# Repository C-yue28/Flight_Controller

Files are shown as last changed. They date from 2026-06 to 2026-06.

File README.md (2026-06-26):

<h1>Custom Flight Controller</h1>

<h3>What is it?</h3>
<p>This is a custom flight controller with onboard LiPo charging capabilities and buck converters for 3V bus as well as support for 6 external motors (3 DC, 3 servo) and 7-pin breakout for external sensor array. USB-UART bus for uploading firmware via serial. Internal power paths for limited high-current motor handling; however most motor wiring will most likely have to be done externally due to PCB limitations.</p>

<h3>Why did I make this?</h3>
<p>Flight has always been something that has fascinated me and so far my only experience has been with assembling premade drone kits or glider kits. I want to be able to go out and fly something that I made essentially from scratch. I have this vision of myself standing on the roof, tossing the plane off, and watching it fly up into the sky, and then looking at the camera feed to see the world from up high.</p>

<h3>Main components/features</h3>
<ol>
  <li>ESP32-S3-WROOM-1U - Central processor</li>
  <li>BMS management circuitry; computer is powered by 3S LiPo battery</li>
  <li>IMU (6-axis; accelerometer/gyroscope)</li>
  <li>Pressure sensor (for altitude)</li>
  <li>OV5640 Camera (external)</li>
  <li>Miscellaneous: external 2.4ghz antenna capability; dual USB-C for charging/data; external microSD support</li>
</ol>

<h3>Firmware brief description</h3>
- Modular handling of all sensors with interrupts configured to save battery power
- Verbose error/initialization logging to detect I2C issues
- Ability to log data to microSD card

<h3>Images</h3>

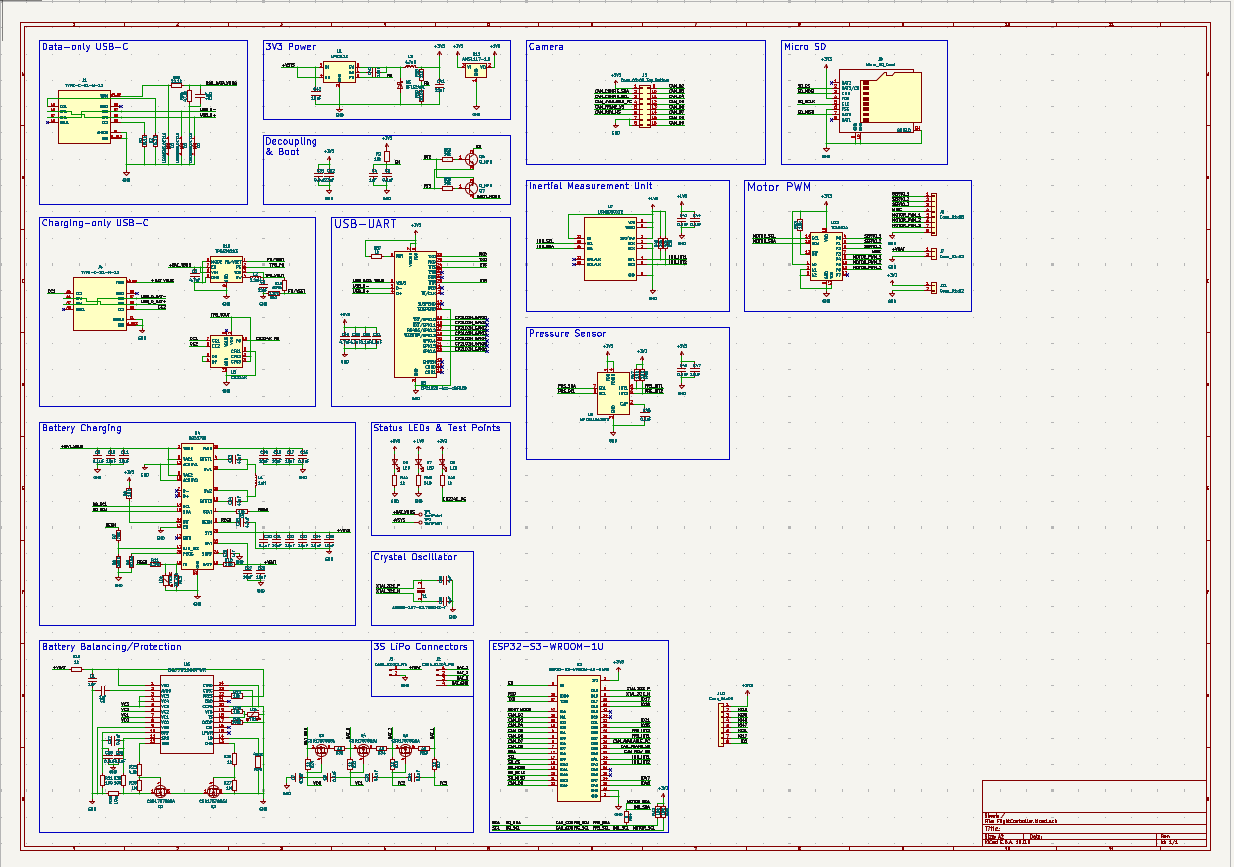
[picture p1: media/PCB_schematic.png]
Schematic


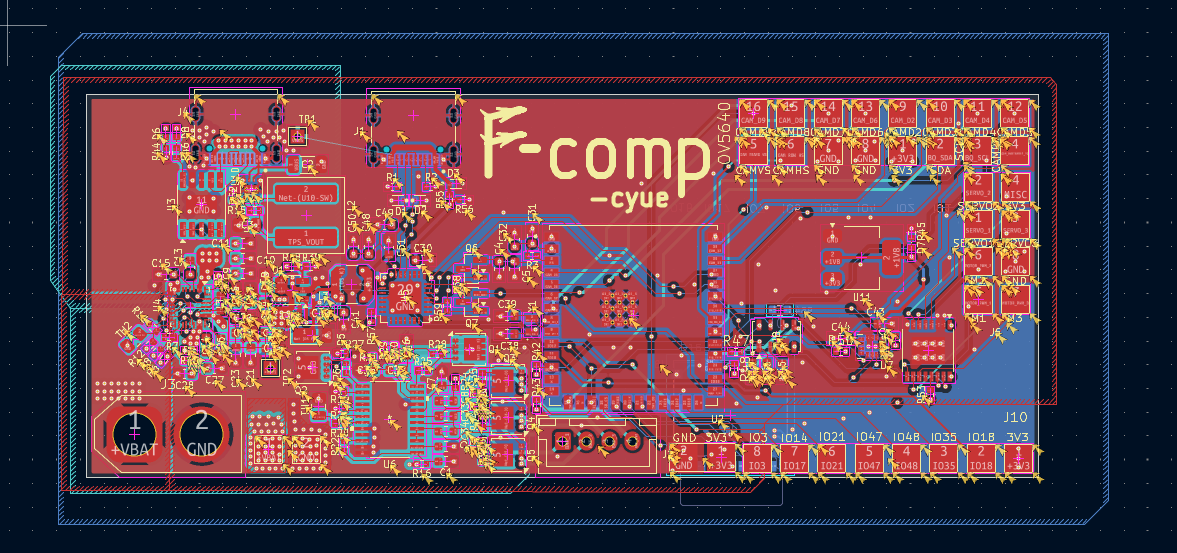
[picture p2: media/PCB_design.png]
PCB design


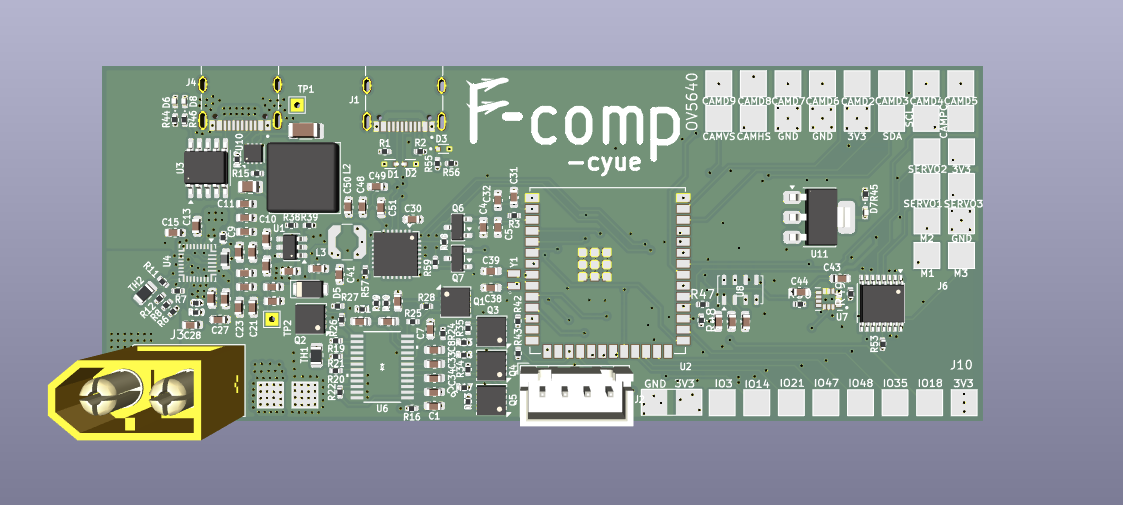
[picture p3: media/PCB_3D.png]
3D Model


<h3>External sources (for the LSM6DSOX firmware libraries)</h3>

[Base LSM6DS Adafruit library](https://github.com/adafruit/Adafruit_LSM6DS/blob/master/examples/adafruit_lsm6ds_unifiedsensors/adafruit_lsm6ds_unifiedsensors.ino)

### Dependencies of this library:

[Adafruit_BusIO](https://github.com/adafruit/Adafruit_BusIO/tree/master)

[Adafruit_Sensor](https://github.com/adafruit/Adafruit_Sensor/tree/master)

<h3>BOM</h3>

| Item | Price | Distributor/Supplier |
|---|---|---|
| PCB | 47.9  | JLCPCB |
| Stencil  | 7.16  | JLCPCB |
| Shipping | 24.15 | JLCPCB |
| Total | 79.21 | |

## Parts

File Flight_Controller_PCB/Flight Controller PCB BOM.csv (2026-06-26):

Designator | Footprint | Quantity | Value | URL | Cost | Notes
C1, C30, C4, C6 | 0603 | 4 | 1uF | https://www.lcsc.com/product-detail/C128624.html | 1.3 | I may already have these
C10, C11, C17, C18, C19, C21, C22, C23, C24, C25, C27, C28, C42 | 0603 | 13 | 10uF | https://www.lcsc.com/product-detail/C22367825.html | 1.16 | I may already have these
C13, C14 | 0603 | 2 | 47nF | 0603B473K500NT | FH | Price | In Stock | LCSC Electronics | 0.61
C15, C48, C49 | 0603 | 3 | 4.7uF | https://www.lcsc.com/product-detail/C5252400.html | 0.45 | I may already have these
C16, C20, C31, C33, C34, C35, C36, C37, C43, C44, C45, C46, C5, C50, C51, C7, C8, C9 | 0603 | 18 | 0.1uF | https://www.lcsc.com/product-detail/C125205.html | 0.81 | I may already have these
C2 | 1206 | 1 | 4.7uF | https://www.lcsc.com/product-detail/C22399656.html | 0.85
C26 | 0603 | 1 | 1nF | https://www.lcsc.com/product-detail/C44369.html | 0.52
C3 | 0805 | 1 | 22uF | (included below) | n/a | I decided to just use a smaller footprint to save some money
C32, C41 | 0603 | 2 | 22uF | https://www.digikey.com/en/products/detail/samsung-electro-mechanics/CL10A226MP8NUNE/3886932 | 0.64
C38, C39 | 0603 | 2 | 4pF | https://www.lcsc.com/product-detail/C1668.html | 0.42
C40 | 0603 | 1 | 10nF | https://www.lcsc.com/product-detail/C100042.html | 0.61
D1, D2, D3 | TVS_LESD5D5.0CT1G | 3 | LESD5D5.0CT1G | https://www.lcsc.com/product-detail/C5246195.html | 0.36
D5 | D_PowerDI-123 | 1 | DFLS240L
D6, D7, D8 | 0402 | 3 | LED | https://www.lcsc.com/product-detail/Light-Emitting-Diodes-LED_YONGYUTAI-YLED0402G_C20608784.html | 0.76
J1, J4 | HRO_TYPE-C-31-M-12 | 2 | TYPE-C-31-M-12 | (I already have these) | n/a
J10, J6 | TestPoint_THTPad_4.0x4.0mm_Drill2.0mm | 2 | Conn_01x08 | n/a
J11, J7 | TestPoint_THTPad_4.0x4.0mm_Drill2.0mm | 2 | Conn_01x02 | n/a
J2 | JST_XH_B4B-XH-A_1x04_P2.50mm_Vertical | 1 | Conn_01x04_Pin | https://www.lcsc.com/product-detail/C144395.html | 0.58
J3 | AMASS_XT60-M_1x02_P7.20mm_Vertical | 1 | Conn_01x02_Pin | https://www.lcsc.com/product-detail/C98733.html | 0.4
J5 | TestPoint_THTPad_2.0x2.0mm_Drill1.0mm | 1 | Conn_02x09_Top_Bottom | n/a
J8 | microSD_HC_Molex_104031-0811 | 1 | Micro_SD_Card | https://www.lcsc.com/product-detail/C585350.html | 0.68
L1 | 0603 | 1 | 1uH | https://www.lcsc.com/product-detail/C5443610.html | 0.42
L2 | 1008 | 1 | 2.2uH | https://www.digikey.com/en/products/detail/shenzhen-sunlord-electronics-co-ltd/SPH252012H2R2MT/14545122 | 0.33
L3 | L_Abracon_ASPI-4030S | 1 | 4.7uH | https://www.digikey.com/en/products/detail/abracon-llc/ASPI-4030S-4R7M-T/4215208 | 0.27
Q1, Q2, Q3, Q4, Q5 | VSON-8_3.3x3.3mm_P0.65mm_NexFET | 5 | CSD17578Q5A | https://www.lcsc.com/product-detail/C2871447.html | 2.41
Q6, Q7 | SOT-23 | 2 | Q_NPN | https://www.lcsc.com/product-detail/C49581.html | 0.79
R1, R2 | 0402 | 2 | 5.1k | https://www.digikey.com/en/products/detail/yageo/RC0402FR-075K1L/726624 | 0.2
R10, R30, R31 | 0402 | 3 | 100 | https://www.digikey.com/en/products/detail/vishay-dale/RCA0402100RFKEDHP/6561236 | 0.3
R11 | 0402 | 1 | 5.24k | https://www.digikey.com/en/products/detail/bourns-inc/CR0402-FX-5231GLF/4698012 | 0.1
R12 | 0402 | 1 | 30.31k | https://www.digikey.com/en/products/detail/vishay-dale/RCS040230K1FKED/5867856 | 0.13
R15 | 0402 | 1 | 619k | https://www.digikey.com/en/products/detail/stackpole-electronics-inc/RMCF0402FT619K/1714833 | 0.1
R16, R17, R18, R23, R24, R26, R44, R46, R57 | 0402 | 9 | 1k | https://www.digikey.com/en/products/detail/vishay/MCS04020C1001FE000/462974 | 0.28 | I may already have these
R19 | 0402 | 1 | 450k | https://www.digikey.com/en/products/detail/vishay-dale/CRCW0402453KFKED/1178309 | 0.1
R20, R22, R3, R42, R43, R49, R5, R50, R53, R58, R59, R9 | 0402 | 12 | 10k | https://www.digikey.com/en/products/detail/vishay-dale/RCA040210K0FKED/4946751 | 0.66 | I may already have these
R21 | 0402 | 1 | 196k | https://www.digikey.com/en/products/detail/stackpole-electronics-inc/RMCF0402FT196K/1761755 | 0.1
R25 | 0402 | 1 | 4.5k | http://digikey.com/en/products/detail/vishay-dale/TNPW04024K53BEED/1606384 | 0.26
R27, R28 | 0402 | 2 | 1M | https://www.digikey.com/en/products/detail/yageo/RC0402FR-071ML/726515 | 0.2
R29 | 0402 | 1 | 10m | https://www.digikey.com/en/products/detail/thin-film-technology-corp/D1MPC0402RR010FF-T10/16735271 | 0.28
R33, R34, R35 | 0805 | 3 | 45 | MBB02070C4539FRP00 (1W, 45.3 OHM): https://www.mouser.com/c/passive-components/resistors/?resistance=45.3%20Ohms&instock=y | 1.14
R38 | 0402 | 1 | 51k | https://www.digikey.com/en/products/detail/stackpole-electronics-inc/RMCF0402FT51K0/2417446 | 0.1
R39 | 0402 | 1 | 16.6k | https://www.digikey.com/en/products/detail/vishay-dale/CRCW040216K9FKEDC/7925759 | 0.1
R45 | 0402 | 1 | 510 | https://www.digikey.com/en/products/detail/koa-speer-electronics-inc/RK73H1ETTP5100F/9844229 | 0.1
R52 | 0402 | 1 | 137k | https://www.digikey.com/en/products/detail/yageo/RC0402FR-07137KL/5280832 | 0.1
R54 | 0603 | 1 | 0 | n/a
R55 | 0402 | 1 | 22.1k | https://www.digikey.com/en/products/detail/yageo/RT0402FRE0722K1L/1071878 | 0.1
R56 | 0402 | 1 | 47.5k | https://www.digikey.com/en/products/detail/yageo/RC0402FR-0747K5L/726617 | 0.1
R6 | 0402 | 1 | 10.5k | https://www.digikey.com/en/products/detail/yageo/RT0402FRE0710K5L/1071707 | 0.1
R7 | 0402 | 1 | 75k | https://www.digikey.com/en/products/detail/yageo/RT0402DRE0775KL/1071646 | 0.1
R8 | 0402 | 1 | 160k | https://www.digikey.com/en/products/detail/stackpole-electronics-inc/RMCF0402FT160K/1714462 | 0.1
TH1, TH2 | 0805 | 2 | 10k | https://www.digikey.com/en/products/detail/tdk/B57471V2103J062/3829885 | 0.62
TP1, TP2 | TestPoint_THTPad_1.5x1.5mm_Drill0.7mm | 2 | TestPoint | n/a
U1 | SOT-23-6 | 1 | AP3211K | https://www.digikey.com/en/products/detail/diodes-incorporated/AP2112K-3-3TRG1/4470746 | 0.25 | I may already have this
U10 | SOT-583-8 | 1 | TPS629203 | https://www.digikey.com/en/products/detail/texas-instruments/TPS629203DRLR/16516661 | 1.08
U11 | SOT-223-3_TabPin2 | 1 | AMS1117-1.8 | https://www.digikey.com/en/products/detail/evvo/AMS1117-1-8/24370064 | 0.3
U12 | TSSOP-16-1EP_4.4x5mm_P0.65mm | 1 | TCA9534 | https://www.digikey.com/en/products/detail/texas-instruments/TCA9534PWR/5004966 | 1.53
U2 | XCVR_ESP32-S3-WROOM-1U-N4R8 | 1 | ESP32-S3-WROOM-1U-N4R8 | https://www.digikey.com/en/products/detail/espressif-systems/ESP32-S3-WROOM-1U-N16R8/16162641 | 6.76
U3 | SSOP-10-1EP_3.9x4.9mm_P1mm_EP2.1x3.3mm | 1 | CH224K | https://www.lcsc.com/product-detail/C970725.html | 0.62
U4 | Texas_RQM0029A_VQFN-29_4x4mm_P0.4mm | 1 | BQ25798 | https://www.digikey.com/en/products/detail/texas-instruments/BQ25798RQMR/15666783 | 5.2
U5 | QFN-28-1EP_5x5mm_P0.5mm_EP3.35x3.35mm | 1 | CP2102N-Axx-xQFN28 | https://www.digikey.com/en/products/detail/silicon-labs/CP2102N-A02-GQFN28/9863477 | 5.1
U6 | PW24_TEX | 1 | BQ7791500PWR | https://www.digikey.com/en/products/detail/texas-instruments/BQ7791500PWR/9593372 | 2.05
U7 | PQFN50P250X300X86-14N | 1 | LSM6DSOXTR | https://estore.st.com/en/lsm6dsotr-cpn.html | 5.32 | LSM6DSOTR
U9 | Bosch_LGA-8_2.5x2.5mm_P0.65mm_ClockwisePinNumbering | 1 | BME280 | https://www.digikey.com/en/products/detail/bosch-sensortec/BME280/6136306 | 4
Y1 | XTAL_ABS06-107-32.768KHZ-T | 1 | ABS06-107-32.768KHZ-T | https://www.digikey.com/en/products/detail/abracon-llc/ABS06-107-32-768KHZ-T/4291565 | 0.83
 |  |  |  |  | 52.78

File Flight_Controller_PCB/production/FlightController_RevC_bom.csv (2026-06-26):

Designator | Footprint | Quantity | Value | LCSC Part #
C1, C30, C4, C6 | 0603 | 4 | 1uF
C10, C11, C17, C18, C19, C21, C22, C23, C24, C25, C27, C28, C42 | 0603 | 13 | 10uF
C13, C14 | 0603 | 2 | 47nF
C15, C48, C49 | 0603 | 3 | 4.7uF
C16, C20, C31, C33, C34, C35, C36, C37, C43, C44, C45, C46, C5, C50, C51, C7, C8, C9 | 0603 | 18 | 0.1uF
C2 | 1206 | 1 | 4.7uF
C26 | 0603 | 1 | 1nF
C3 | 0805 | 1 | 22uF
C32, C41 | 0603 | 2 | 22uF
C38, C39 | 0603 | 2 | 4pF
C40 | 0603 | 1 | 10nF
D1, D2, D3 | TVS_LESD5D5.0CT1G | 3 | LESD5D5.0CT1G
D5 | D_PowerDI-123 | 1 | DFLS240L
D6, D7, D8 | 0402 | 3 | LED
J1, J4 | HRO_TYPE-C-31-M-12 | 2 | TYPE-C-31-M-12
J10, J6 | TestPoint_THTPad_4.0x4.0mm_Drill2.0mm | 2 | Conn_01x08
J11, J7 | TestPoint_THTPad_4.0x4.0mm_Drill2.0mm | 2 | Conn_01x02
J2 | JST_XH_B4B-XH-A_1x04_P2.50mm_Vertical | 1 | Conn_01x04_Pin
J3 | AMASS_XT60-M_1x02_P7.20mm_Vertical | 1 | Conn_01x02_Pin
J5 | TestPoint_THTPad_2.0x2.0mm_Drill1.0mm | 1 | Conn_02x09_Top_Bottom
J8 | microSD_HC_Molex_104031-0811 | 1 | Micro_SD_Card
L1 | 0603 | 1 | 1uH
L2 | 1008 | 1 | 2.2uH
L3 | L_Abracon_ASPI-4030S | 1 | 4.7uH
Q1, Q2, Q3, Q4, Q5 | VSON-8_3.3x3.3mm_P0.65mm_NexFET | 5 | CSD17578Q5A
Q6, Q7 | SOT-23 | 2 | Q_NPN
R1, R2 | 0402 | 2 | 5.1k
R10, R30, R31 | 0402 | 3 | 100
R11 | 0402 | 1 | 5.24k
R12 | 0402 | 1 | 30.31k
R15 | 0402 | 1 | 619k
R16, R17, R18, R23, R24, R26, R44, R46, R57 | 0402 | 9 | 1k
R19 | 0402 | 1 | 450k
R20, R22, R3, R42, R43, R49, R5, R50, R53, R58, R59, R9 | 0402 | 12 | 10k
R21 | 0402 | 1 | 196k
R25 | 0402 | 1 | 4.5k
R27, R28 | 0402 | 2 | 1M
R29 | 0402 | 1 | 10m
R33, R34, R35 | 0805 | 3 | 45
R38 | 0402 | 1 | 51k
R39 | 0402 | 1 | 16.6k
R45 | 0402 | 1 | 510
R52 | 0402 | 1 | 137k
R54 | 0603 | 1 | 0
R55 | 0402 | 1 | 22.1k
R56 | 0402 | 1 | 47.5k
R6 | 0402 | 1 | 10.5k
R7 | 0402 | 1 | 75k
R8 | 0402 | 1 | 160k
TH1, TH2 | 0805 | 2 | 10k
TP1, TP2 | TestPoint_THTPad_1.5x1.5mm_Drill0.7mm | 2 | TestPoint
U1 | SOT-23-6 | 1 | AP3211K
U10 | SOT-583-8 | 1 | TPS629203
U11 | SOT-223-3_TabPin2 | 1 | AMS1117-1.8
U12 | TSSOP-16-1EP_4.4x5mm_P0.65mm | 1 | TCA9534
U2 | XCVR_ESP32-S3-WROOM-1U-N4R8 | 1 | ESP32-S3-WROOM-1U-N4R8
U3 | SSOP-10-1EP_3.9x4.9mm_P1mm_EP2.1x3.3mm | 1 | CH224K
U4 | Texas_RQM0029A_VQFN-29_4x4mm_P0.4mm | 1 | BQ25798
U5 | QFN-28-1EP_5x5mm_P0.5mm_EP3.35x3.35mm | 1 | CP2102N-Axx-xQFN28
U6 | PW24_TEX | 1 | BQ7791500PWR
U7 | PQFN50P250X300X86-14N | 1 | LSM6DSOXTR
U9 | Bosch_LGA-8_2.5x2.5mm_P0.65mm_ClockwisePinNumbering | 1 | BME280
Y1 | XTAL_ABS06-107-32.768KHZ-T | 1 | ABS06-107-32.768KHZ-T

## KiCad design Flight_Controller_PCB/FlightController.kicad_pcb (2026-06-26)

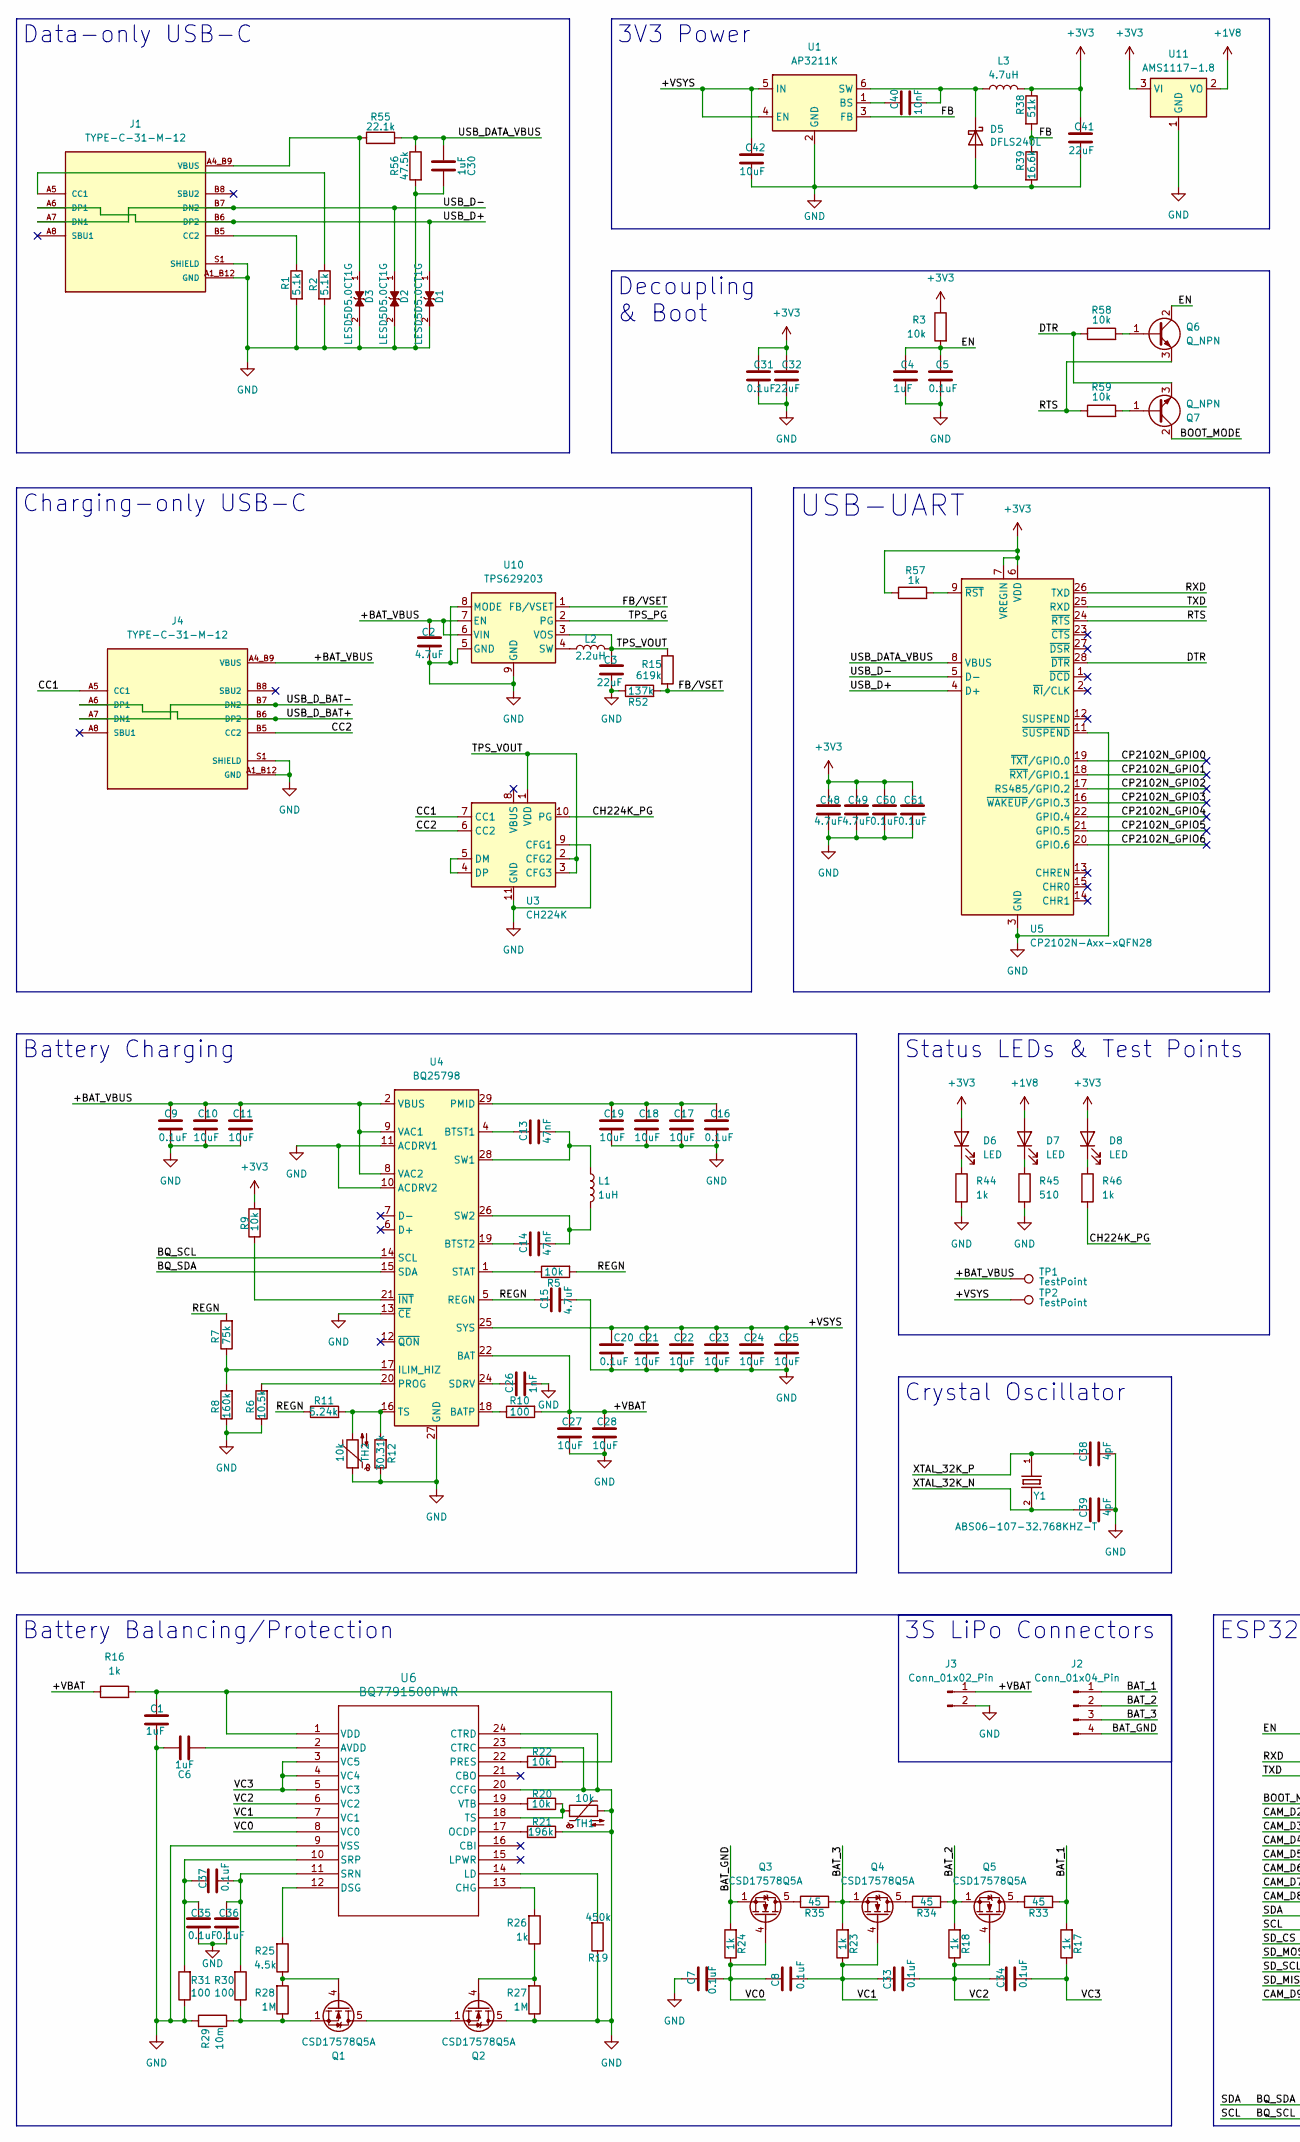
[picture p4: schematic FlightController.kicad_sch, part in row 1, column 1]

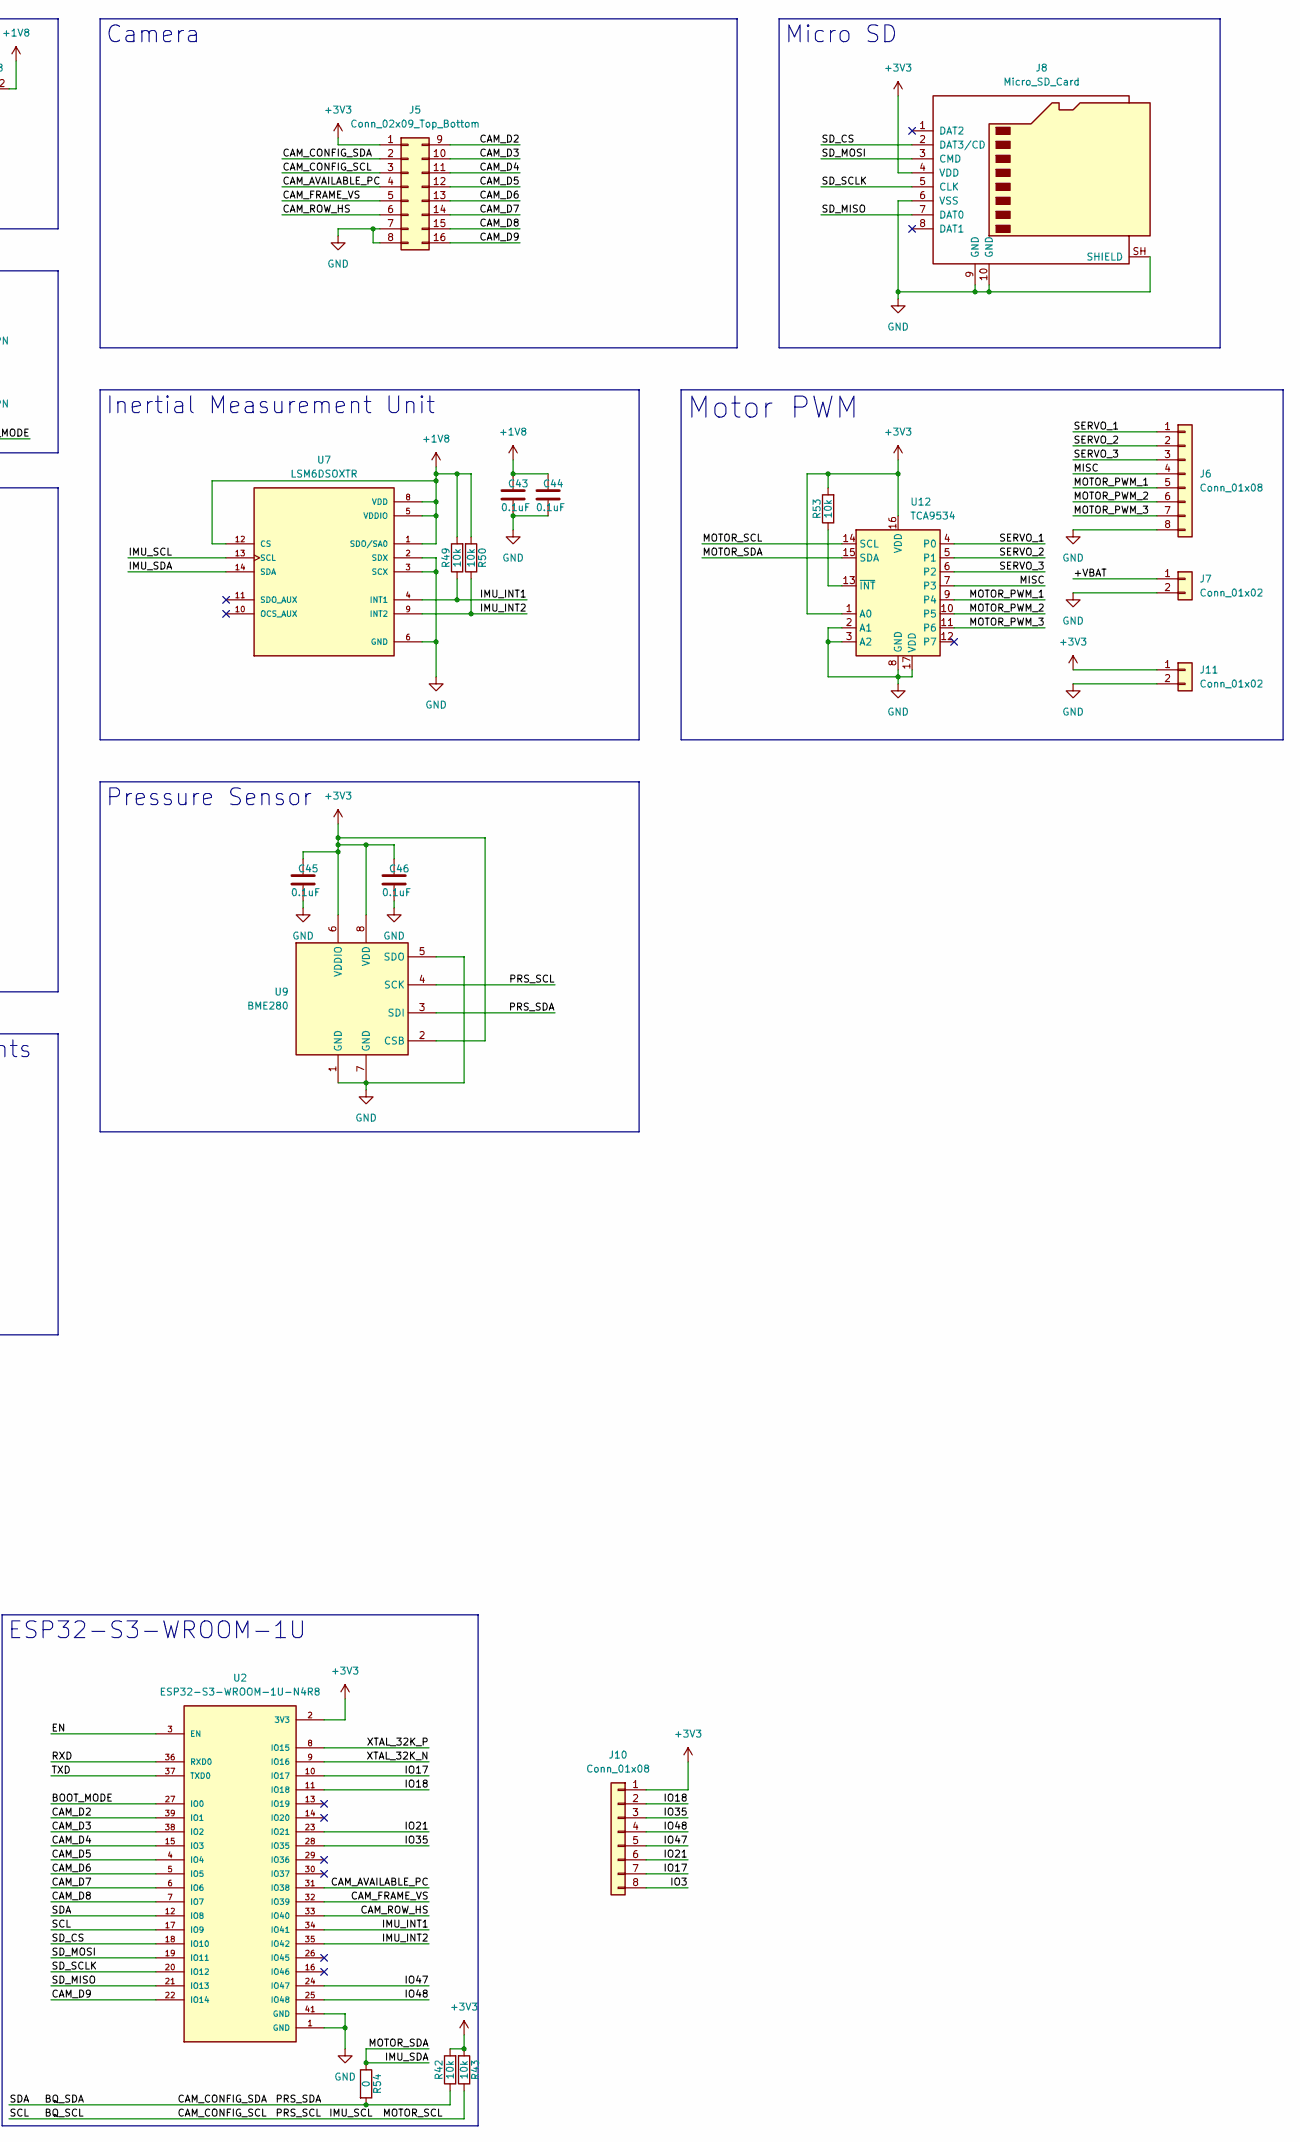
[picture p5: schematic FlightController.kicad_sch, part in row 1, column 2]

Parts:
C1, C4, C6, C30: 1uF; C_0603_1608Metric
C2: 4.7uF; C_1206_3216Metric
C3: 22uF; C_0805_2012Metric
C5, C7, C8, C9, C16, C20, C31, C33, C34, C35, C36, C37, C43, C44, C45, C46, C50, C51: 0.1uF; C_0603_1608Metric
C10, C11, C17, C18, C19, C21, C22, C23, C24, C25, C27, C28, C42: 10uF; C_0603_1608Metric
C13, C14: 47nF; C_0603_1608Metric
C15, C48, C49: 4.7uF; C_0603_1608Metric
C26: 1nF; C_0603_1608Metric
C32, C41: 22uF; C_0603_1608Metric
C38, C39: 4pF; C_0603_1608Metric
C40: 10nF; C_0603_1608Metric
D1, D2, D3: LESD5D5.0CT1G; TVS_LESD5D5.0CT1G; PARTREV O
D5: DFLS240L; D_PowerDI-123
D6, D7, D8: LED; LED_0402_1005Metric
J1, J4: TYPE-C-31-M-12; HRO_TYPE-C-31-M-12; PARTREV 2020.12.08
J2: Conn_01x04_Pin; JST_XH_B4B-XH-A_1x04_P2.50mm_Vertical
J3: Conn_01x02_Pin; AMASS_XT60-M_1x02_P7.20mm_Vertical
J5: Conn_02x09_Top_Bottom; TestPoint_THTPad_2.0x2.0mm_Drill1.0mm
J6, J10: Conn_01x08; TestPoint_THTPad_4.0x4.0mm_Drill2.0mm
J7, J11: Conn_01x02; TestPoint_THTPad_4.0x4.0mm_Drill2.0mm
J8: Micro_SD_Card; microSD_HC_Molex_104031-0811
L1: 1uH; L_0603_1608Metric
L2: 2.2uH; L_1008_2520Metric
L3: 4.7uH; L_Abracon_ASPI-4030S
Q1, Q2, Q3, Q4, Q5: CSD17578Q5A; VSON-8_3.3x3.3mm_P0.65mm_NexFET
Q6, Q7: Q_NPN; SOT-23
R1, R2: 5.1k; R_0402_1005Metric
R3, R5, R9, R20, R22, R42, R43, R49, R50, R53, R58, R59: 10k; R_0402_1005Metric
R6: 10.5k; R_0402_1005Metric
R7: 75k; R_0402_1005Metric
R8: 160k; R_0402_1005Metric
R10, R30, R31: 100; R_0402_1005Metric
R11: 5.24k; R_0402_1005Metric
R12: 30.31k; R_0402_1005Metric
R15: 619k; R_0402_1005Metric
R16, R17, R18, R23, R24, R26, R44, R46, R57: 1k; R_0402_1005Metric
R19: 450k; R_0402_1005Metric
R21: 196k; R_0402_1005Metric
R25: 4.5k; R_0402_1005Metric
R27, R28: 1M; R_0402_1005Metric
R29: 10m; R_0402_1005Metric
R33, R34, R35: 45; R_0805_2012Metric_Pad1.20x1.40mm_HandSolder
R38: 51k; R_0402_1005Metric
R39: 16.6k; R_0402_1005Metric
R45: 510; R_0402_1005Metric
R52: 137k; R_0402_1005Metric
R54: 0; R_0603_1608Metric
R55: 22.1k; R_0402_1005Metric
R56: 47.5k; R_0402_1005Metric
TH1, TH2: 10k; R_0805_2012Metric
TP1, TP2: TestPoint; TestPoint_THTPad_1.5x1.5mm_Drill0.7mm
U1: AP3211K; SOT-23-6
U2: ESP32-S3-WROOM-1U-N4R8; XCVR_ESP32-S3-WROOM-1U-N4R8; PARTREV v1.1; DigiKey_Part_Number 1965-ESP32-S3-WROOM-1U-N4R8CT-ND
U3: CH224K; SSOP-10-1EP_3.9x4.9mm_P1mm_EP2.1x3.3mm
U4: BQ25798; Texas_RQM0029A_VQFN-29_4x4mm_P0.4mm
U5: CP2102N-Axx-xQFN28; QFN-28-1EP_5x5mm_P0.5mm_EP3.35x3.35mm
U6: BQ7791500PWR; PW24_TEX
U7: LSM6DSOXTR; PQFN50P250X300X86-14N; PARTREV 3.0; DigiKey_Part_Number 497-18367-1-ND
U9: BME280; Bosch_LGA-8_2.5x2.5mm_P0.65mm_ClockwisePinNumbering
U10: TPS629203; SOT-583-8
U11: AMS1117-1.8; SOT-223-3_TabPin2
U12: TCA9534; TSSOP-16-1EP_4.4x5mm_P0.65mm
Y1: ABS06-107-32.768KHZ-T; XTAL_ABS06-107-32.768KHZ-T; DigiKey_Part_Number 535-12373-1-ND

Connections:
+1V8: C43.1, C44.1, D7.2 (A), R49.2, R50.2, U7.1 (SDO/SA0), U7.5 (VDDIO), U7.8 (VDD), U7.12 (CS), U11.2 (VO)
+3V3: C31.1, C32.1, C41.1, C45.1, C46.1, C48.1, C49.1, C50.1, C51.1, D6.2 (A), D8.2 (A), J5.1, J8.4 (VDD), J10.1, J11.1, L3.2, R3.1, R9.2, R38.1, R42.2, R43.2, R53.2, R57.1, U2.2 (3V3), U5.6 (VDD), U5.7 (VREGIN), U9.2 (CSB), U9.6 (VDDIO), U9.8 (VDD), U11.3 (VI), U12.1 (A0), U12.16 (VDD)
/+VBAT: C27.1, C28.1, J3.1, J7.1, R10.2, R16.1, U4.22 (BAT), U4.23 (BAT)
/+VSYS: C20.1, C21.1, C22.1, C23.1, C24.1, C25.1, C42.1, TP2.1 (1_1), U1.4 (EN), U1.5 (IN), U4.25 (SYS)
/BAT_1: J2.1, R17.2, R33.2
/BAT_2: J2.2, Q5.1 (S), Q5.2 (S), Q5.3 (S), R18.2, R34.2
/BAT_3: J2.3, Q4.1 (S), Q4.2 (S), Q4.3 (S), R23.2, R35.2
/BAT_GND: J2.4, Q3.1 (S), Q3.2 (S), Q3.3 (S), R24.2
/BOOT_MODE: Q7.2 (C), U2.27 (IO0)
/BQ_SCL: J5.3, R43.1, U2.17 (IO9), U4.14 (SCL), U7.13 (SCL), U9.4 (SCK), U12.14 (SCL)
/BQ_SDA: J5.2, R42.1, R54.2, U2.12 (IO8), U4.15 (SDA), U9.3 (SDI)
/CAM_AVAILABLE_PC: J5.4, U2.31 (IO38)
/CAM_D2: J5.9, U2.39 (IO1)
/CAM_D3: J5.10, U2.38 (IO2)
/CAM_D4: J5.11, U2.15 (IO3)
/CAM_D5: J5.12, U2.4 (IO4)
/CAM_D6: J5.13, U2.5 (IO5)
/CAM_D7: J5.14, U2.6 (IO6)
/CAM_D8: J5.15, U2.7 (IO7)
/CAM_D9: J5.16, U2.22 (IO14)
/CAM_FRAME_VS: J5.5, U2.32 (IO39)
/CAM_ROW_HS: J5.6, U2.33 (IO40)
/CC1: J4.A5 (CC1), U3.7 (CC1)
/CC2: J4.B5 (CC2), U3.6 (CC2)
/CH224K_PG: R46.2, U3.10 (PG)
/CP2102N_GPIO0: U5.19 (~TXT/GPIO.0)
/CP2102N_GPIO1: U5.18 (~RXT/GPIO.1)
/CP2102N_GPIO2: U5.17 (RS485/GPIO.2)
/CP2102N_GPIO3: U5.16 (~WAKEUP/GPIO.3)
/CP2102N_GPIO4: U5.22 (GPIO.4)
/CP2102N_GPIO5: U5.21 (GPIO.5)
/CP2102N_GPIO6: U5.20 (GPIO.6)
/DTR: Q7.3 (E), R58.1, U5.28 (~DTR)
/EN: C4.1, C5.1, Q6.2 (C), R3.2, U2.3 (EN)
/FB: R38.2, R39.1, U1.3 (FB)
/FB/VSET: R15.2, R52.2, U10.1 (FB/VSET)
/IMU_INT1: R49.1, U2.34 (IO41), U7.4 (INT1)
/IMU_INT2: R50.1, U2.35 (IO42), U7.9 (INT2)
/IMU_SDA: R54.1, U7.14 (SDA), U12.15 (SDA)
/IO3: J10.8
/IO17: J10.7, U2.10 (IO17)
/IO18: J10.2, U2.11 (IO18)
/IO21: J10.6, U2.23 (IO21)
/IO35: J10.3, U2.28 (IO35)
/IO47: J10.5, U2.24 (IO47)
/IO48: J10.4, U2.25 (IO48)
/MISC: J6.4, U12.7 (P3)
/MOTOR_PWM_1: J6.5, U12.9 (P4)
/MOTOR_PWM_2: J6.6, U12.10 (P5)
/MOTOR_PWM_3: J6.7, U12.11 (P6)
/REGN: C15.1, R5.2, R7.2, R11.1, U4.5 (REGN)
/RTS: Q6.3 (E), R59.1, U5.24 (~RTS)
/RXD: U2.36 (RXD0), U5.26 (TXD)
/SD_CS: J8.2 (DAT3/CD), U2.18 (IO10)
/SD_MISO: J8.7 (DAT0), U2.21 (IO13)
/SD_MOSI: J8.3 (CMD), U2.19 (IO11)
/SD_SCLK: J8.5 (CLK), U2.20 (IO12)
/SERVO_1: J6.1, U12.4 (P0)
/SERVO_2: J6.2, U12.5 (P1)
/SERVO_3: J6.3, U12.6 (P2)
/TPS_PG: U10.2 (PG)
/TPS_VOUT: C3.1, L2.1, R15.1, U3.1 (VDD), U3.2 (CFG2), U3.3 (CFG3), U10.3 (VOS)
/TXD: U2.37 (TXD0), U5.25 (RXD)
/USB_D+: D1.1, J1.A6 (DP1), J1.B6 (DP2), U5.4 (D+)
/USB_D-: D2.1, J1.A7 (DN1), J1.B7 (DN2), U5.5 (D-)
/USB_DATA_VBUS: C30.2, R55.2, R56.1, U5.8 (VBUS)
/USB_D_BAT+: J4.A6 (DP1), J4.B6 (DP2)
/USB_D_BAT-: J4.A7 (DN1), J4.B7 (DN2)
/VC0: C7.2, C8.2, Q3.4 (G), R24.1, U6.8 (VC0)
/VC1: C8.1, C33.2, Q4.4 (G), R23.1, U6.7 (VC1)
/VC2: C33.1, C34.2, Q5.4 (G), R18.1, U6.6 (VC2)
/VC3: C34.1, R17.1, U6.3 (VC5), U6.4 (VC4), U6.5 (VC3)
/XTAL_32K_N: C39.1, U2.9 (IO16), Y1.2
/XTAL_32K_P: C38.1, U2.8 (IO15), Y1.1
GND: C1.2, C2.2, C3.2, C4.2, C5.2, C6.1, C7.1, C9.2, C10.2, C11.2, C15.2, C16.2, C17.2, C18.2, C19.2, C20.2, C21.2, C22.2, C23.2, C24.2, C25.2, C26.2, C27.2, C28.2, C30.1, C31.2, C32.2, C35.1, C36.1, C38.2, C39.2, C41.2, C42.2, C43.2, C44.2, C45.2, C46.2, C48.2, C49.2, C50.2, C51.2, D1.2, D2.2, D3.2, D5.2 (A), J1.A1_B12 (GND), J1.B1_A12 (GND), J1.S1 (SHIELD), J1.S2 (SHIELD), J1.S3 (SHIELD), J1.S4 (SHIELD), J3.2, J4.A1_B12 (GND), J4.B1_A12 (GND), J4.S1 (SHIELD), J4.S2 (SHIELD), J4.S3 (SHIELD), J4.S4 (SHIELD), J5.7, J5.8, J6.8, J7.2, J8.6 (VSS), J8.9 (GND), J8.10 (GND), J8.SH (SHIELD), J11.2, Q2.5 (D), R1.2, R2.2, R6.1, R8.1, R12.1, R19.1, R21.1, R27.1, R29.2, R31.1, R39.2, R44.2, R45.2, R52.1, R56.2, TH1.2, TH2.1, U1.2 (GND), U2.1 (GND), U2.40 (GND), U2.41 (GND), U2.41_1 (GND), U2.41_2 (GND), U2.41_3 (GND), U2.41_4 (GND), U2.41_5 (GND), U2.41_6 (GND), U2.41_7 (GND), U2.41_8 (GND), U2.41_9 (GND), U3.9 (CFG1), U3.11 (GND), U4.10 (ACDRV2), U4.11 (ACDRV1), U4.13 (~CE), U4.27 (GND), U5.3 (GND), U5.11 (~SUSPEND), U5.29 (GND), U6.9 (VSS), U6.20 (CCFG), U6.23 (CTRC), U6.24 (CTRD), U7.2 (SDX), U7.3 (SCX), U7.6 (GND), U7.7 (GND), U9.1 (GND), U9.5 (SDO), U9.7 (GND), U10.5 (GND), U10.8 (MODE), U10.9 (GND), U11.1 (GND), U12.2 (A1), U12.3 (A2), U12.8 (GND), U12.17 (VDD)
unnamed: C40.2, D5.1 (K), L3.1, U1.6 (SW)
unnamed: D6.1 (K), R44.1
unnamed: D7.1 (K), R45.1
unnamed: D8.1 (K), R46.1
unnamed: J1.A5 (CC1), R2.1
unnamed: J1.B5 (CC2), R1.1
unnamed: Q1.5 (D), Q2.1 (S), Q2.2 (S), Q2.3 (S)
unnamed: Q1.4 (G), R25.1, R28.2
unnamed: Q1.1 (S), Q1.2 (S), Q1.3 (S), R28.1, R29.1, R30.1
unnamed: Q2.4 (G), R26.1, R27.2
unnamed: Q3.5 (D), R35.1
unnamed: Q4.5 (D), R34.1
unnamed: Q5.5 (D), R33.1
unnamed: Q6.1 (B), R58.2
unnamed: Q7.1 (B), R59.2
unnamed: C40.1, U1.1 (BS)
unnamed: U3.4 (DP), U3.5 (DM)
unnamed: R10.1, U4.18 (BATP)
unnamed: C13.1, U4.4 (BTST1)
unnamed: C14.1, U4.19 (BTST2)
unnamed: R7.1, R8.2, U4.17 (ILIM_HIZ)
unnamed: C16.1, C17.1, C18.1, C19.1, U4.29 (PMID)
unnamed: R6.2, U4.20 (PROG)
unnamed: C26.1, U4.24 (SDRV)
unnamed: R5.1, U4.1 (STAT)
unnamed: C13.2, L1.1, U4.28 (SW1)
unnamed: C14.2, L1.2, U4.26 (SW2)
unnamed: R11.2, R12.2, TH2.2, U4.16 (TS)
unnamed: R9.1, U4.21 (~INT)
unnamed: R57.2, U5.9 (~RST)
unnamed: C6.2, U6.2 (AVDD)
unnamed: R26.2, U6.13 (CHG)
unnamed: R25.2, U6.12 (DSG)
unnamed: R19.2, U6.14 (LD)
unnamed: R21.2, U6.17 (OCDP)
unnamed: R22.2, U6.22 (PRES)
unnamed: C36.2, C37.1, R30.2, U6.11 (SRN)
unnamed: C35.2, C37.2, R31.2, U6.10 (SRP)
unnamed: R20.1, TH1.1, U6.18 (TS)
unnamed: C1.1, R16.2, R22.1, U6.1 (VDD)
unnamed: R20.2, U6.19 (VTB)
unnamed: L2.2, U10.4 (SW)
unnamed: R53.1, U12.13 (~INT)

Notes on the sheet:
3S LiPo Connectors
ESP32-S3-WROOM-1U
Micro SD
Motor PWM
Camera
USB-UART
Decoupling & Boot
Data-only USB-C
Inertial Measurement Unit
Pressure Sensor
Battery Balancing/Protection
Battery Charging
3V3 Power
Charging-only USB-C
Crystal Oscillator
Status LEDs & Test Points

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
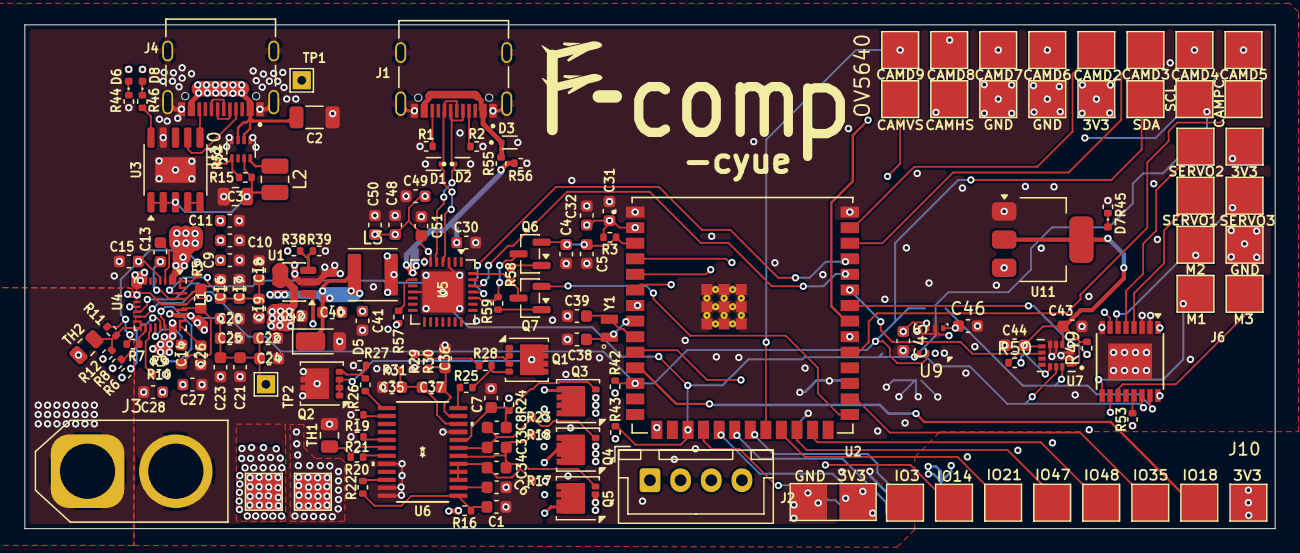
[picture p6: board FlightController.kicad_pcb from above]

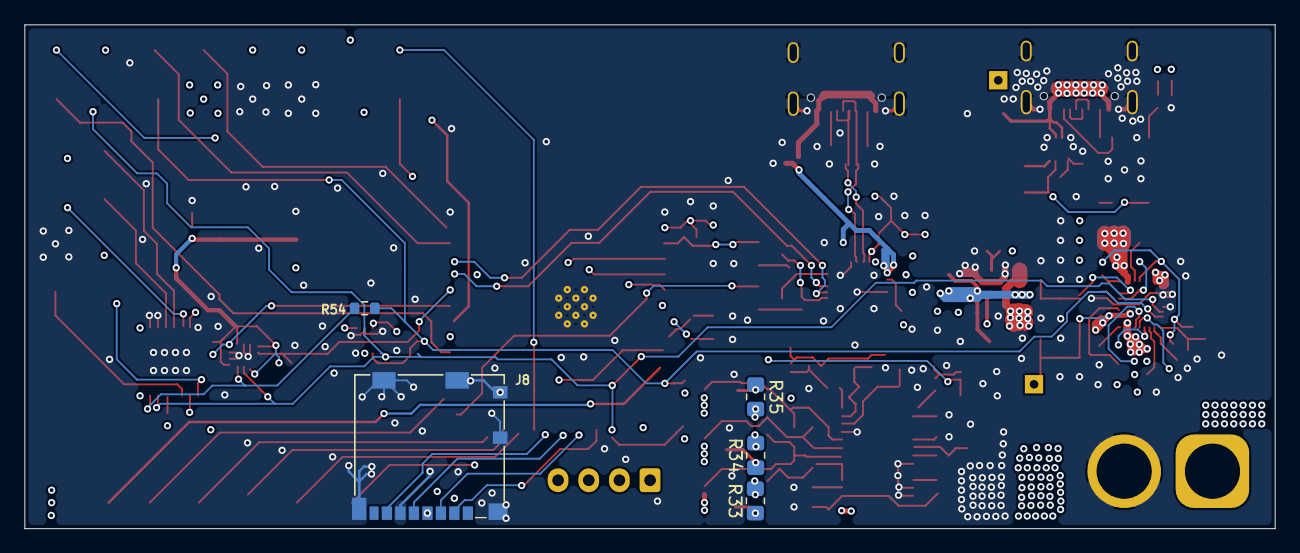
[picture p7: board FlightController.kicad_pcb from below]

Board: 6 copper layers, 102.0 x 41.1 mm, 139 parts (5 on the bottom side), 110 nets.

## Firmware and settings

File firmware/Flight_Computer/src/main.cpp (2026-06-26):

#include <Arduino.h>
#include <Wire.h>
#include <SD.h>
#include <SPI.h>

// Personal libraries
#include <BQ25798.h>
#include <TCA9534.h>
#include <OV5640.h>
#include <BME280.h>

// Open-source libraries
#include <Adafruit_LSM6DSOX.h>

#define ESP32_ADDR 0x67

// I2C pins

#define SDA 8
#define SCL 9

#define NUM_I2C_DEVICES 5
#define MAX_I2C_INIT_LOOPS 10

// External SD card

#define SD_CS 10
#define SD_MOSI 11
#define SD_SCK 12
#define SD_MISO 13

// Camera: OV5640

#define CAM_D2 1
#define CAM_D3 2
#define CAM_D4 3
#define CAM_D5 4
#define CAM_D6 5
#define CAM_D7 6
#define CAM_D8 7
#define CAM_D9 14
#define CAM_AVAIL_PC 38
#define CAM_FRAME_VS 39
#define CAM_ROW_HS 40

// IMU: LSM6DSOX
#define IMU_I2C_ADDR 0b1101011

#define IMU_INT1 41
#define IMU_INT2 42

// Motor handling
#define SERVO_1 0
#define SERVO_2 1
#define SERVO_3 2
#define MOTOR_1 4
#define MOTOR_2 5
#define MOTOR_3 6

#define PWM_FREQUENCY 1 // 1 tick, or 1 ms per bit on the output lines to ESC

// I2C  

BQ25798 charger(&Wire);
TCA9534 motorController(&Wire);
BME280 bme280(&Wire);
Adafruit_LSM6DSOX imu;
Adafruit_Sensor *imu_temp, *imu_gyro, *imu_accel;

sensors_vec_t rotation;
sensors_vec_t acceleration;
sensors_event_t imu_temp_event;

TaskHandle_t pwmHandle = NULL;

typedef struct {
  uint8_t pin;
  float pwm_duty;
} motorControlConfig;

bool initI2C();
int detectI2CDevices();

bool writeFile(const char *path, const char *data, bool overwrite = false);
uint8_t* readFile(const char *path);

void readIMUData(uint8_t intNum);
void outputPWM(void *pvParameters);

void setup() {

  Serial.begin(115200);
  while (!Serial);

  Serial.print("Serial initialized\n");

  if (!initI2C()) {
    Serial.println("I2C initialization failed");
    return;
  }
  Serial.println("I2C initialized");

  // SD card

  if (!SD.begin(SD_CS)) {
    Serial.println("SD initialization failed");
    return;
  } else {
    Serial.println("SD initialized successfully");
  }

  // run the motors at 25% speed
  motorControlConfig* initial_pwm_config = new motorControlConfig();
  initial_pwm_config->pwm_duty = 0.25;
  for (int i = MOTOR_1; i < MOTOR_3; i++) {
    initial_pwm_config->pin = i;
    xTaskCreatePinnedToCore(outputPWM, "PWM", 4096, (void*)initial_pwm_config, 1, NULL, 0);
  }

}

// Unit tests

/* OV5640

void loop() {
  camera_fb_t *fb = esp_camera_fb_get();
  
  if (!fb) {
      Serial.println("Camera capture failed!");
      delay(1000);
      return;
  }

  Serial.printf("Captured image! Size: %d bytes, Width: %d, Height: %d\n", fb->len, fb->width, fb->height);

  esp_camera_fb_return(fb); 
  
  delay(100); 
}

*/

/* Motors

void loop() {
  motorControlConfig* cfg = new motorControlConfig();
  cfg->pwm_duty = 0.5;
  for (int i = MOTOR_1; i < MOTOR_3; i++) {
    cfg->pin = i;
    xTaskCreatePinnedToCore(outputPWM, "PWM", 4096, cfg, 1, NULL, 0);
  }
  
  cfg->pwm_duty = 0.0;
  for (int i = MOTOR_1; i < MOTOR_3; i++) {
    cfg->pin = i;
    xTaskCreatePinnedToCore(outputPWM, "PWM", 4096, cfg, 1, NULL, 0);
  }
}

*/

/* BME280

void loop() {
  Serial.printf("Temperature: %f C\n", bme280.getTemperature());
  Serial.printf("Pressure: %f Pa\n", bme280.getPressure());
  Serial.printf("Humidity: %f %%\n", bme280.getHumidity());
  vTaskDelay(2000 / portTICK_PERIOD_MS);
}

*/

/* IMU

void loop() {
  Serial.printf("Temperature: %f C\n", altimeter.getTemperature() + imu_temp_event.temperature);
  Serial.printf("Rotation: %f rad/s, %f rad/s, %f rad/s\n", rotation.x, rotation.y, rotation.z);
  Serial.printf("Acceleration: %f m/s^2, %f m/s^2, %f m/s^2\n", acceleration.x, acceleration.y, acceleration.z);
  vTaskDelay(2000 / portTICK_PERIOD_MS);
}

*/

bool initI2C() {
  bool success_I2C = Wire.begin(SDA, SCL);
  if (success_I2C) {
    Serial.println("I2C initialized");
  } else {
    Serial.println("I2C initialization failed");
    return false;
  }

  int numDevices = detectI2CDevices();
  int loops = 0;
  while (numDevices < NUM_I2C_DEVICES) {
    Serial.printf("%d devices found\n", numDevices);
    Serial.println("Not enough I2C devices found, rechecking in 5 seconds");
    delay(5000);
    numDevices = detectI2CDevices();
    loops++;
    if (loops > MAX_I2C_INIT_LOOPS) {
      Serial.println("Max I2C init loops reached, stopping program");
      return false;
    }
  }
  Serial.printf("Successfully detected %d devices!\n", numDevices);

  // I2C device initialization

  // BQ25798

  if (charger.begin()) {
    Serial.println("BQ25798 initialized");
  } else {
    Serial.println("BQ25798 initialization failed");
    return false;
  }

  if (charger.initialize3SDefaults()) {
    Serial.println("BQ25798 3S defaults initialized");
  } else {
    Serial.println("BQ25798 3S defaults initialization failed");
    return false;
  }

  // OV5640

  if (initializeCamera(
    CAM_D2, CAM_D3, CAM_D4, CAM_D5,
    CAM_D6, CAM_D7, CAM_D8, CAM_D9,
    CAM_AVAIL_PC, CAM_FRAME_VS, CAM_ROW_HS,
    SDA, SCL,
    -1, -1
  )) {
    Serial.println("OV5640 initialized");
  } else {
    Serial.println("OV5640 initialization failed");
    return false;
  }

  // TCA9534
  motorController.begin();
  Serial.println("TCA9534 initialized");

  // BME280
  bme280.begin();
  Serial.println("BME280 initialized");

  // IMU
  if (!imu.begin_I2C(IMU_I2C_ADDR)) {
    Serial.println("Failed to initialize IMU!");
    return false;
  }
  Serial.println("IMU initialized");

  imu.configIntOutputs(true, true);
  imu.configInt1(true, true, false, false, false);
  imu.configInt2(false, false, true);

  pinMode(IMU_INT1, OUTPUT_OPEN_DRAIN | INPUT);
  pinMode(IMU_INT2, OUTPUT_OPEN_DRAIN | INPUT);

  attachInterrupt(digitalPinToInterrupt(IMU_INT1), []() { readIMUData(0x00); }, LOW);
  attachInterrupt(digitalPinToInterrupt(IMU_INT2), []() { readIMUData(0x01); }, LOW);

  Serial.println("IMU interrupts configured");

  imu_temp = imu.getTemperatureSensor();
  imu_temp->printSensorDetails();

  imu_accel = imu.getAccelerometerSensor();
  imu_accel->printSensorDetails();

  imu_gyro = imu.getGyroSensor();
  imu_gyro->printSensorDetails();

  Serial.println("IMU sensors configured");

  return true;

}

int detectI2CDevices() {

  byte error, address;
  int nDevices = 0;

  Serial.println("Scanning for devices...");

  for (address = 1; address < 127; address++) {
    Wire.beginTransmission(address);
    error = Wire.endTransmission();

    if (error == 0) {
      Serial.print("I2C device found at address 0x");
      Serial.println(address, HEX);
      nDevices++;
    } else if (error == 4) {
      Serial.print("Unknown error at address 0x");
      Serial.println(address, HEX);
    }
  }

  return nDevices;

}

bool writeFile(const char *path, const char *data, bool overwrite) {
  Serial.printf("Writing to file: %s\n", path);
  File file = SD.open(path, FILE_WRITE);
  if (file) {
    file.print(data);
    file.close();
    Serial.println("Write succeeded");
    return true;
  } else {
    Serial.println("Failed to write");
    return false;
  }
}


uint8_t* readFile(const char *path) {
  Serial.printf("Reading file: %s\n", path);
  File file = SD.open(path);
  size_t len = file.size();
  uint8_t* buffer = (uint8_t*)malloc(len+1);
  if (file) {
    file.read(buffer, len);
    buffer[len] = '\0';
    file.close();
  } else {
    Serial.println("Failed to read");
    return NULL;
  }
  return buffer;
}

void readIMUData(uint8_t intNum) {
  Serial.printf("IMU interrupt %d triggered\n", intNum+1);
  if (intNum == 0x00) {
    sensors_event_t gyro;
    imu_temp->getEvent(&imu_temp_event);
    imu_gyro->getEvent(&gyro);

    rotation = gyro.gyro;

    Serial.printf("Temperature: %.2f C\n", imu_temp_event.temperature);
    Serial.printf("Gyro: %.2f rad/s, %.2f rad/s, %.2f rad/s\n", rotation.x, rotation.y, rotation.z);
  } else {
    sensors_event_t accel;
    imu_accel->getEvent(&accel);

    acceleration = accel.acceleration;

    Serial.printf("Acceleration: %.2f m/s^2, %.2f m/s^2, %.2f m/s^2\n", acceleration.x, acceleration.y, acceleration.z);
  }
}

void outputPWM(void* pvParameters) {
  motorControlConfig* temp_config = (motorControlConfig*)pvParameters;
  motorControlConfig config;
  config.pin = temp_config->pin;
  config.pwm_duty = temp_config->pwm_duty;
  // Send 8-bit PWM after sending arbitrary 8-bit address - change to 4-bit later?
 
  TickType_t xLastWakeTime = xTaskGetTickCount();

  for (int i = 0; i < 8; i++) {
    motorController.digitalWrite(config.pin, (ESP32_ADDR >> i) & 0x01);
    vTaskDelayUntil(&xLastWakeTime, PWM_FREQUENCY);
  }
  
  uint8_t pwm_bits = (uint8_t)(config.pwm_duty * 255);
  xLastWakeTime = xTaskGetTickCount();

  for (int i = 0; i < 8; i++) {
    motorController.digitalWrite(config.pin, (pwm_bits >> i) & 0x01);
    vTaskDelayUntil(&xLastWakeTime, PWM_FREQUENCY);
  }

  motorController.digitalWrite(config.pin, LOW);
}

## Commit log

2026-05-10 First flight controller PCB commit
    [FlightController.kicad_pcb, FlightController.kicad_sch]
2026-06-19 Finished building BQ25798 library, compile successful
    [FlightController.kicad_pcb, FlightController.kicad_sch, FlightController_RevB_bom.csv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]
2026-06-19 OV5640 configuration completed, build successful
    [FlightController.kicad_pcb, FlightController.kicad_sch, FlightController_RevC_bom.csv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]
2026-06-21 Sourced LSM6DSOX library from GitHub and wrote basic data-gathering firmware, wrote library for pressure sensor, fixed compile issues
    [main.cpp]
2026-06-21 Added motor control logic, implemented digital PWM, wrote unit tests, added data logging and verbose initialization logging
2026-06-21 Added media, added STEP file of PCB
    [FlightController.kicad_pcb, FlightController.kicad_sch, FlightController_RevB_bom.csv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]
2026-06-26 Replaced MPL altimeter with BME280 pressure/temp/humidity sensor
    [main.cpp]
2026-06-26 Add BOM
2026-06-26 Finalize for submission and add BOM
    [BOM.csv, Flight Controller PCB BOM.csv, FlightController.kicad_pcb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]
